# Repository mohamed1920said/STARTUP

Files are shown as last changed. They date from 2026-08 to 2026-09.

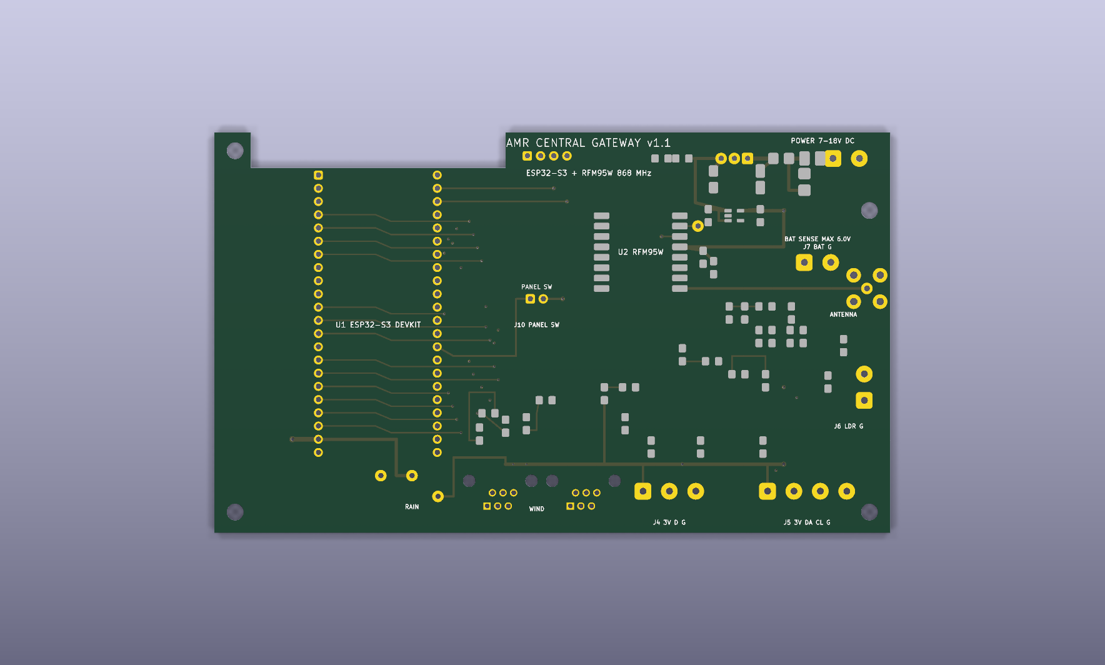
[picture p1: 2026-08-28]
hardware/central_gateway/renders/central_gateway_top.png

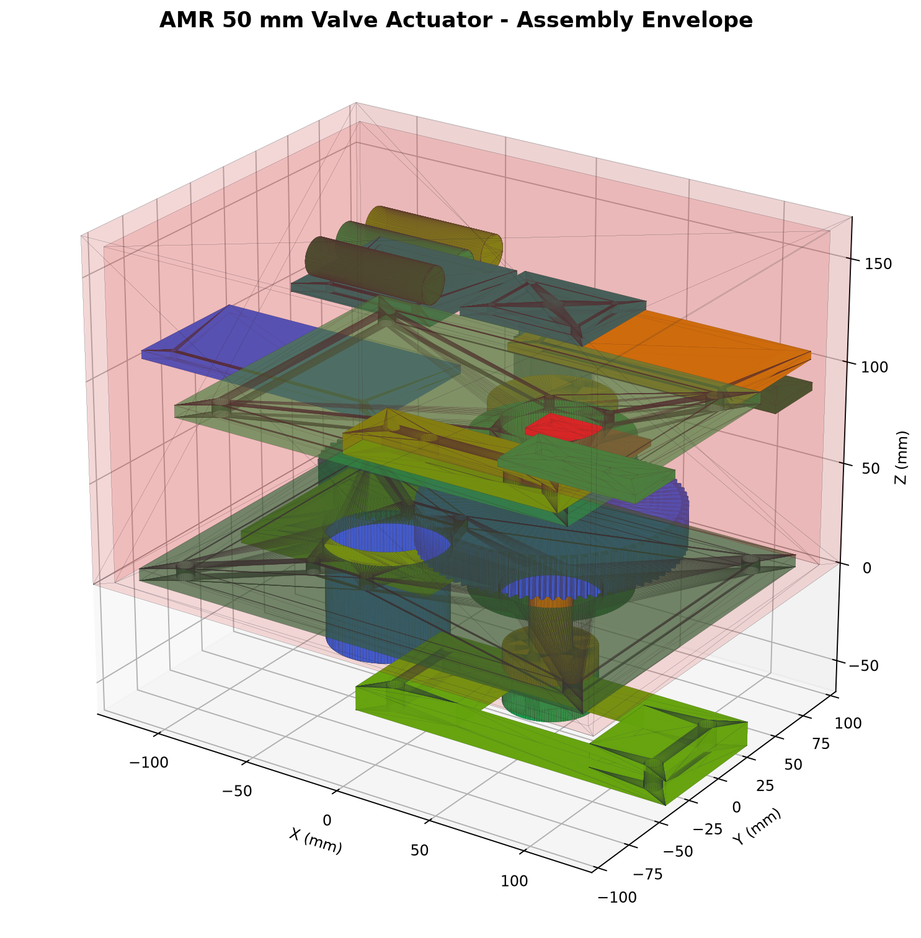
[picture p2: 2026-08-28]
hardware/actuator/cad/renders/AMR_50mm_Valve_Actuator.png

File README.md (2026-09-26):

# AMR LoRa Irrigation System

Supervised-pilot firmware for three device roles:

- ESP32-S3 central gateway
- TTGO LoRa32 soil sensor node
- TTGO LoRa32 actuator/valve node

The gateway receives AES-128-GCM encrypted LoRa telemetry at 868 MHz, serves a local dashboard, runs guarded irrigation rules and an offline ESP32-S3 Edge-AI advisor, controls actuators, records a versioned AI-ready dataset, and optionally connects to an HTTPS cloud API. Cloud control is CLOSE-only, while local MQTT and browser firmware upload are disabled by default for the supervised pilot.

## Firmware environments

| Environment | Hardware | Purpose |
|---|---|---|
| `central_gateway` | ESP32-S3-DevKitC-1-N8 | Gateway, dashboard, weather and optional cloud bridge |
| `sensor_node` | TTGO LoRa32 v2.1 | Soil moisture, DS18B20 temperature and battery telemetry |
| `actuator_node` | TTGO LoRa32 v2.1 | Fail-safe latching-valve control, verified feedback and hydraulic telemetry |

## Wi-Fi setup

1. Power the central gateway.
2. Read the generated commissioning password from the physical 115200-baud serial console.
3. Connect to the WPA2-protected `STARTUP-Gateway-xxxxxx` Wi-Fi network using that password.
4. Open `http://192.168.4.1`.
5. Select farm Wi-Fi and create an 8–32 character dashboard administrator password.
6. After restart, sign in to the dashboard with username `admin` and the configured password.

Use an isolated pilot network. The dashboard, REST API and WebSocket use HTTP Basic authentication. Gateway firmware updates use physical USB in this build.

LoRa reception, local automation, actuator safety and CSV logging continue when
farm Wi-Fi or internet access is unavailable. Dashboard and cloud access
resume after the gateway can boot on the configured farm network.

## Build

```powershell
pio run -e central_gateway -e sensor_node -e actuator_node
pio run -e central_gateway -t buildfs
```

`platformio.ini` pins Espressif32 platform `7.0.1` and exact tested library versions. Do not loosen those constraints for a pilot image; rebuild and repeat the deployment checklist after any dependency change.

## Upload the ESP32-S3 gateway

```powershell
pio run -e central_gateway -t upload --upload-port COM4
pio run -e central_gateway -t uploadfs --upload-port COM4
```

`flash_central.bat COM4` performs both gateway uploads.

This release changes the gateway partition table. The first installation must
upload both firmware and filesystem; uploading only one will leave the
dashboard or partition layout inconsistent.

## Important protocol rule

Gateway, sensor and actuator firmware must be upgraded together. This revision sends the full 16-byte AES-GCM authentication tag; firmware using the former 4-byte tag cannot communicate with it. ACK is 10 bytes and actuator heartbeat is 17 bytes. Persistent sequence reservations and replay checkpoints are written and read back before use; storage failure suppresses transmission or rejects the command/packet instead of continuing without replay protection.

## Node commissioning

Sensor and actuator images contain no default node ID or PSK. Provision each node over its physical USB serial connection, then add the exact same ID, type and unique 16-byte PSK in the gateway dashboard. Duplicate gateway IDs are refused. Reprovisioning requires explicit removal and a newly generated PSK. An unprovisioned or corrupt node keeps its radio disabled, and gateway OPEN remains blocked until it receives a fresh authenticated packet after provisioning. Never clear or clone the preserved `lora_seq` state while reusing a PSK; generate a new PSK after a full NVS erase.

See the [supervised pilot deployment guide](docs/PILOT_DEPLOYMENT.md) for provisioning commands, cloud endpoints and the required bench and field validation.

## Prototype data collection

The authenticated dashboard's **AI Dataset** panel provides:

- raw and centrally calibrated moisture values;
- UTC epoch time, boot ID, uptime and packet sequence for traceability;
- weather, valve commands, verified valve state, ACKs and optional hydraulics;
- crop, growth-stage and soil metadata per sensor zone;
- field event labels such as rain, leak, blockage and valve fault;
- current and previous CSV downloads.

Configure each sensor's real dry/wet ADC endpoints before collecting training
data. The gateway keeps two rolling 1.25 MiB CSV segments as an outage buffer.
Download both segments regularly or configure the HTTPS cloud connection for a
multi-week dataset. See [AI dataset guide](docs/AI_DATASET.md).

Hydraulic inputs are intentionally disabled by default. Wire and calibrate the
real sensors, then build the actuator with `-DENABLE_HYDRAULIC_SENSORS=1`.

## Edge AI

The central gateway now contains a compact trained model bank for irrigation
need, water/runtime recommendation, rain-delay scheduling, soil dry-down,
watering-effect verification, fault detection and next-day weather prediction.
The dashboard **Edge AI** panel explains each zone recommendation.

AI control is deliberately compiled off with `EDGE_AI_ALLOW_CONTROL=0`. The
model runs in shadow mode while the normal threshold controller and actuator
safety limits remain independent. See [Edge-AI model and deployment guide](docs/EDGE_AI.md).

## Project layout

```text
data/                 Dashboard HTML, JavaScript and CSS
docs/                 Current architecture, wiring and security references
hardware/central_gateway/ KiCad 10 carrier PCB, BOM, clean DRC and fabrication files
lib/                  Required Wi-Fi, dashboard, LoRa protocol and crypto libraries
src/central/          ESP32-S3 gateway firmware
src/sensor/           Soil sensor firmware
src/actuator/         Fail-safe valve actuator firmware
platformio.ini        Three retained PlatformIO environments
partitions_8MB.csv     Gateway OTA + 3.375 MiB LittleFS partition map
flash_central.bat     Windows gateway upload helper
upload_guide.txt      Upload commands and recovery notes
```

## Pilot safety limits

Automatic mode can be enabled only after valid valve feedback received within 90 seconds. Invalid sensor data cancels an automatic OPEN that may still be in flight; invalid or stale data retries CLOSE until fresh feedback verifies commanded and physical state are closed. A failed safety enqueue remains eligible at the next pass without starting its throttle; a normal threshold-driven automatic CLOSE retries after five seconds. Pending tracking rejects duplicate live OPENs and never replaces one to make room. The actuator rejects OPEN below 3400 mV or above an implausible 5000 mV reading; CLOSE remains allowed. OPEN is capped at 300 seconds, the build rejects any higher configured cap, and repeated OPEN commands do not extend the active deadline. Failed OPEN feedback verification immediately sends CLOSE and retries it if necessary.

This does not authorize unattended irrigation. A latching valve needs energy to close, software cannot prove water stopped without independent feedback, and the cloud queue is RAM-only with no automatic CSV backlog replay. Keep a physical master shutoff accessible and complete `docs/PILOT_DEPLOYMENT.md` before any wet pilot.

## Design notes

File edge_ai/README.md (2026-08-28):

# Edge-AI training tools

`train_edge_ai.py` trains the compact ESP32-S3 model bank from the Tunisia CSV,
writes `model_manifest.json` and `metrics.json`, and regenerates
`src/central/EdgeAIModel.h`.

`test_edge_ai.py` checks the training hash, model dimensions, dry-versus-wet
behaviour, finite weather forecasts and injected-fault recognition.

`preview_dashboard.py` is a localhost-only visual fixture server for dashboard
QA; it is never included in the ESP32 filesystem image.

See `docs/EDGE_AI.md` for architecture, metrics, safety gates and deployment.

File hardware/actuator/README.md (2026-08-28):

# AMR 50 mm Quarter-Turn Valve Actuator

This directory contains a prototype mechanical design for a 50 mm PVC ball-valve actuator. The gearbox is reusable for a future 63 mm valve; only the lower clamp and measured stem adapter change.

## Release status

Revision `A-PROTOTYPE` is suitable for fit checks, bench testing, and controlled field prototypes. It is **not released for unattended irrigation or sale** until every hold point in `RELEASE_CHECKLIST.md` is closed and the completed actuator passes torque, ingress, electrical, and endurance tests.

The real 5840-31ZY motor and PVC valve were not supplied for measurement. Their interfaces are intentionally marked `HOLD - MEASURE` in the native SolidWorks custom properties and documentation.

## Delivered CAD

- `cad/native/`: 27 manufactured `.SLDPRT` files, purchased-component reference parts, and the resolved 35-component `.SLDASM`.
- `cad/step/`: individual STEP parts and the complete placed STEP assembly.
- `cad/stl/`: printable gears, sensor carriers, trays, and enclosure components.
- `cad/dxf/`: laser/CNC profiles for plates, brackets, and the 50/63 mm clamp variants.
- `cad/renders/`: assembled and exploded verification views plus gear-profile SVGs.
- `cad/motion/`: the verified 6-second open/close GIF, poster, and validation report. Raw viewport frames are deleted after encoding.
- `bom/`: mechanical, material/electrical, and fastener BOMs.

The placed neutral assembly contains 35 components in the 50 mm configuration (the alternative 63 mm clamp is delivered separately). `tools/validate_neutral_assembly.py` performs exact solid-intersection checks and writes `manufacturing/ASSEMBLY_GEOMETRY_VALIDATION.json`. The individual manufactured parts are native feature-based SolidWorks files. Gear bodies use exact 20-degree involute STEP solids generated by `tools/generate_neutral_cad.py` and imported into native parts because the installed SolidWorks 2026 sketch API was unstable on high-segment gear profiles.

The native assembly contains a Basic Motion study named `AMR_Valve_Open_Close`. It drives the 40T motor gear through 180 degrees and the output shaft group through 90 degrees over a 6-second oscillating cycle. The study uses 10 rotary motor features so the output gear, shaft, clutch stack, valve adapter, magnet carrier, reed cam, and manual override remain synchronized. The cover is present in the saved assembly and is suppressed only in the GIF preview.

## Key design values

| Parameter | Value |
|---|---:|
| Valve rotation | 90 degrees |
| Motor gear | 40 teeth, module 1.5, 20-degree pressure angle |
| Output gear | 80 teeth, module 1.5, 20-degree pressure angle |
| Gear ratio | 2:1 |
| Centre distance | 90.00 mm |
| Practical mesh backlash | 0.30 mm total |
| Motor/output gear OD | 63 / 123 mm |
| Nominal output speed | 20 rpm no-load |
| Theoretical 90-degree time | 0.75 s no-load |
| Output shaft | 20 mm, 4140 or stainless |
| Bearings | 2 x 6204-2RS, 20 x 47 x 14 mm |
| Bearing spacing | 59 mm between bearing centres |
| Initial clutch target | 8 N m |
| Production clutch target | 1.5 x measured valve breakaway torque, limited by weakest component |
| Structural plates | 6 mm 6061-T6 |
| Enclosure intent | IP65 minimum, IP67 preferred after testing |

## Mechanical architecture

The 20 mm shaft carries a four-bolt lower flange. A replaceable stem adapter bolts to that flange, so a different stem profile or valve size does not require a new gearbox. Two 16 mm aluminium bearing carriers provide real 6204 seats and internal retainers; the 6 mm structural plates only locate and support the carriers.

The output gear runs on a metal sleeve around the hub and transmits torque through two friction faces. M16 Belleville preload is adjusted until the clutch opens the measured valve reliably and slips before the weakest protected component. The steel M8 stops sit beyond the electronic targets and hard-limit switches.

The requested 19 mm external manual hex cannot physically surround a 20 mm shaft. The manufacturable design uses a 30 mm external hex, 20.2 mm bore, and cross-pin. Engaging manual mode must open a hardware interlock that disables both BTS7960 enable lines.

## Position and safety sequence

1. AS5600 target at calibrated 0 or 90 degrees.
2. Independent reed confirmation near 2 and 88 degrees.
3. Normally-closed hard-limit switch at approximately 0 and 90 degrees.
4. Adjustable steel stop at approximately -1 and 91 degrees.
5. Friction clutch slip.

Hard limits and the manual-mode switch must disable motor-driver control in hardware; software monitoring is additional protection, not the only protection.

## Electronics compatibility warning

The repository's current `src/actuator/main.cpp` drives a short-pulse latching valve through a TB6612FNG. It is **not compatible** with this continuous 12 V 5840-31ZY/BTS7960 actuator. Do not connect this motor to the current firmware. The required I/O and interlock architecture is documented in `INTERFACE_CONTROL.md`.

## Rebuilding

1. Install SolidWorks 2026 with the standard part and assembly templates.
2. Install Python 3.12 and `cadquery==2.6.1`.
3. Run `python tools/generate_neutral_cad.py` to create exact gears, DXFs, neutral assembly, and renders.
4. Run `python tools/validate_neutral_assembly.py`; release only when unintended intersections are zero.
5. Run `cscript //nologo tools/generate_solidworks.vbs <project-root> parts-only`.
6. Run `powershell -ExecutionPolicy Bypass -File tools/build_motion_study.ps1`; this builds the direct native assembly, creates the Basic Motion study, closes and reopens SolidWorks to validate it, captures the cover-off viewport frames, and encodes the GIF preview.
7. Confirm `cad/motion/AMR_Valve_Open_Close_REPORT.txt` ends with `RESULT=PASS`, reports 35 components, 10 motion features after calculation, a 6-second duration, and gear-centre translation below 0.01 mm.
8. Regenerate the drawing pack with `python tools/generate_documentation.py`.

## Required reading

- `ASSEMBLY_INSTRUCTIONS.md`
- `INTERFACE_CONTROL.md`
- `RELEASE_CHECKLIST.md`
- `output/pdf/AMR_Valve_Actuator_Manufacturing_Pack.pdf`

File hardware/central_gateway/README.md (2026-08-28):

# AMR Central Gateway PCB

KiCad 10 carrier board for the AMR central gateway firmware. The board accepts an
ESP32-S3-DevKitC-1-N8R8, adds a soldered RFM95W 868 MHz radio, protected sensor
interfaces, regulated 7-18 V input, an enclosure-button connector, service UART,
and test points.

## Status

- Board revision: `v1.1-prototype`
- Board size: 130 mm x 77 mm, including the ESP32 antenna clearance notch
- Copper layers: 4
- Modular jack footprint: Wuerth Elektronik `615006138421`, manufacturer geometry
- Manufacturing outputs: `manufacturing/central_gateway-fabrication.zip`

The saved DRC result and manufacturing files must be regenerated after every
generator change. This remains a prototype, not a certified production product.
Before sale or outdoor deployment, complete an independent electrical review, RF
tuning, EMC/pre-compliance, surge/EFT/ESD, temperature, and enclosure-ingress tests.

## Physical connector architecture

- J2 is a six-position RJ11-compatible modular jack for the tipping-bucket rain gauge.
- J3 is one six-position RJ11-compatible modular jack for the combined wind cable: wind vane
  plus cup-anemometer reed switch.
- J4 is a three-pin screw terminal for the DHT sensor.
- J5 is a four-pin screw terminal for the BMP280/I2C sensor.
- J6 is a two-pin screw terminal for a passive LDR.
- U2, the RFM95W LoRa module, is soldered directly to the PCB. Its SPI signals are
  intentionally not routed through a screw terminal. J9 is its SMA antenna port.
- The setup/reset button is mounted in the enclosure and wired to J10. There is no
  pushbutton mounted on the PCB.

## Main design choices

- Replaceable ESP32-S3 DevKitC-1 for prototype programming and repair.
- RFM95W-868S2 with a short SMA feed for Tunisia's 868 MHz LoRa deployment.
- 7-18 V input with resettable fuse, SMBJ18A surge clamp, SS34 reverse-polarity
  protection, and R-78E5.0-1.0 5 V regulator.
- AP2112K 3.3 V rail for radio and sensors.
- ESD protection and series resistance on all external sensor signals.
- 100 kOhm / 100 kOhm battery divider matching `WeatherStation.cpp`.
- Dedicated inner ground plane plus bottom ground pour.
- No carrier PCB beneath the ESP32-S3 module antenna.

## Layer stack

| Layer | Use |
|---|---|
| F.Cu | Components, local signals, RF feed |
| In1.Cu | Continuous GND plane |
| In2.Cu | DevKit fan-out and crossing signals |
| B.Cu | Power/signal routing with GND pour |

Order a 1.6 mm, four-layer FR-4 board with at least 1 oz external copper. The
0.45 mm antenna trace is only a prototype starting width. Recalculate the 50 ohm
RF geometry using the fabricator's actual stack-up before production.

## Connector pinout

Pin 1 is the square pad. Modular-jack pin numbers below are PCB contact numbers,
not cable colors; verify the purchased cable continuity before connecting it.

| Connector | PCB pin order | Purpose |
|---|---|---|
| J1 | 1 `VIN_RAW`, 2 `GND` | 7-18 V DC input |
| J2 | 1 NC, 2 NC, 3 `GND`, 4 `RAIN_RAW`, 5 NC, 6 NC | Rain gauge; center pair only |
| J3 | 1 NC, 2 `VANE_RAW`, 3 `GND`, 4 `WIND_RAW`, 5 `GND`, 6 NC | Combined vane + anemometer 6P4C cable |
| J4 | 1 `3V3`, 2 `DHT_RAW`, 3 `GND` | DHT11/DHT22 |
| J5 | 1 `3V3`, 2 `SDA`, 3 `SCL`, 4 `GND` | BMP280 / I2C sensor |
| J6 | 1 `LDR_RAW`, 2 `GND` | Passive LDR; PCB provides 10 kOhm pull-up |
| J7 | 1 `BAT+`, 2 `GND` | 0-6.0 V measurement input only |
| J8 | 1 `3V3`, 2 `GND`, 3 `UART_TX`, 4 `UART_RX` | 3.3 V service UART |
| J9 | center RF, shell `GND` | SMA for tuned 868 MHz antenna |
| J10 | 1 `SETUP_RESET`, 2 `GND` | Enclosure-mounted normally-open button |

Do not power the system through J7 and never apply more than 6.0 V to it. J8 is
3.3 V logic and is not 5 V tolerant. Never apply external voltage to J10: the
panel button must only short pins 1 and 2.

## Weather-kit electrical behavior

- Rain: each bucket tip closes the reed switch and represents 0.2794 mm.
- Wind speed: one closure per second represents approximately 2.4 km/h, or
  0.667 m/s.
- Wind direction: the vane exposes a 16-position resistor network. The firmware
  lookup is calculated for the PCB's 3.3 V, 10 kOhm pull-up; verify and calibrate
  the ADC centers on assembled production hardware.

## Firmware-to-board map

| Function | ESP32-S3 GPIO | PCB net |
|---|---:|---|
| LoRa NSS | 18 | `LORA_NSS` |
| LoRa DIO0 | 2 | `LORA_DIO0` |
| LoRa reset | 14 | `LORA_RST` |
| LoRa SCK / MOSI / MISO | 12 / 11 / 13 | `LORA_SCK` / `LORA_MOSI` / `LORA_MISO` |
| Rain | 6 | `RAIN_GPIO` |
| Wind pulse | 3 | `WIND_GPIO` |
| Wind vane ADC | 10 | `VANE_ADC` |
| DHT data | 7 | `DHT_GPIO` |
| LDR ADC | 9 | `LDR_ADC` |
| Battery ADC | 8 | `BATT_ADC` |
| I2C SDA / SCL | 4 / 5 | `I2C_SDA_GPIO` / `I2C_SCL_GPIO` |
| Wi-Fi setup reset | 0 | `SETUP_RESET` |

Hold the enclosure button for five seconds to request the Wi-Fi setup reset.
GPIO0 is also a boot-strapping pin, so do not hold the button while applying
power or resetting the DevKit unless firmware-download mode is intended.

## Assembly and verification

- TP1: +5 V
- TP2: +3.3 V peripheral rail
- TP3: GND
- TP4: LoRa DIO1

Before fitting U1 or U2, power the carrier from a current-limited bench supply and
verify TP1 and TP2. Fit the ESP32 module, then fit the RFM95W and connect its
antenna before transmitting. Continuity-test both weather cables to confirm their
contact order before plugging them into J2/J3.

Observe diode polarity. D1 cathode connects to `VIN_FUSED`; D2 anode connects to
`VIN_FUSED` and cathode to `VIN_PROTECTED`. For D3-D10, confirm the purchased
part's polarity and marking against the schematic and datasheet.

## Regeneration and verification

From the repository root:

```powershell
python hardware\central_gateway\generate_kicad.py
& 'C:\Program Files\KiCad\10.0\bin\kicad-cli.exe' pcb upgrade hardware\central_gateway\central_gateway.kicad_pcb
& 'C:\Program Files\KiCad\10.0\bin\kicad-cli.exe' pcb drc --refill-zones --save-board --severity-all --format report --output hardware\central_gateway\central_gateway-drc.rpt hardware\central_gateway\central_gateway.kicad_pcb
```

The routed PCB and deterministic generator are authoritative. The legacy
schematic is a compact circuit-review reference and is converted by KiCad on
first open.

## Production checklist

1. Verify the exact DevKit, Wuerth jacks, screw terminals, JST header, and panel
   button against purchased samples and the final enclosure.
2. Confirm cable pinout and add keying/labels so rain and wind plugs cannot be
   exchanged in the field.
3. Tune RF geometry for the chosen stack-up and test the installed antenna/VNA
   performance inside the final enclosure.
4. Validate regulator temperature and brownout margin at maximum Wi-Fi/LoRa load.
5. Test all external ports for the required IEC ESD, EFT, and surge environment.
6. Use a UV-resistant IP65/IP67 enclosure, strain relief, suitable glands or
   sealed panel couplers, conformal coating where appropriate, and fused power.
7. Run a pilot build and production functional-test fixture before volume manufacture.

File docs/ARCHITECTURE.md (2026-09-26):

# AMR System Architecture

## Pilot scope

The maintained build contains one ESP32-S3 central gateway and TTGO LoRa32
sensor/actuator nodes. It is configured for a supervised pilot: Edge AI remains in
shadow mode, local MQTT and browser OTA are disabled, automatic OPEN requires
verified valve-position feedback, cloud control is CLOSE-only, and one OPEN period
is capped at 300 seconds. Compile-time checks prevent a higher configured cap.

```text
Soil sensor nodes -- authenticated LoRa telemetry --> ESP32-S3 gateway
ESP32-S3 gateway -- authenticated LoRa commands --> actuator nodes
Actuator nodes -- authenticated ACK/heartbeat --> ESP32-S3 gateway
Weather sensors --> ESP32-S3 gateway
ESP32-S3 gateway --> authenticated local dashboard + rolling CSV
ESP32-S3 gateway --> optional CA-validated HTTPS cloud API
```

## Central gateway runtime

The Arduino framework runs on ESP-IDF/FreeRTOS. The gateway creates:

- LoRa task: core 1, priority 4, 4096-byte stack.
- Cloud task: core 0, priority 1, 8192-byte stack.
- Dataset task: core 0, priority 1, 6144-byte stack.
- LoRa TX queue: 8 entries.
- Pending command correlation: 32 slots for up to 16 provisioned nodes.
- Cloud request queue: 64 volatile entries.
- Dataset queue: 48 typed records.
- State mutex for persistent downlink sequences and pending commands.

The Arduino loop services Wi-Fi, dashboard maintenance, weather collection, Edge AI
and the automatic controller. LoRa reception, safety logic, and rolling CSV logging
continue without farm Wi-Fi or internet. The setup AP is WPA2 protected with the
generated password printed only on the physical serial console. The farm-network
dashboard uses HTTP Basic authentication; deploy it on an isolated pilot network.

The HTTPS queue retries briefly but is held in RAM. Restart discards queued requests,
and the gateway does not replay CSV records to the cloud. Current and previous CSV
segments remain the outage evidence and must be exported separately.

Cloud `VALVE_ON` commands receive a negative ACK without radio transmission.
`VALVE_OFF` remains enabled. The gateway caches 32 tuples of command ID, target node,
and requested state in RAM. Exact completed duplicates return the cached ACK;
reusing a numeric ID for another node/state is a separate request. Completion also
requires the same tuple, so a delayed old actuator result cannot overwrite a newer
request. A fast ACK that completes the tuple before cloud-pending bookkeeping finishes
cannot downgrade `COMPLETE` back to `PENDING`. The parser validates identifiers before
narrowing them: `command_id` is an integer in 1..`UINT32_MAX`, and `node_id` is an
integer in 1..65534. Invalid values are rejected rather than wrapping to another node.
Rejected commands return a negative ACK, and a pending CLOSE can retry after 30
seconds. The cloud service must still guarantee unique command IDs because this cache
does not survive restart.

## Radio configuration and frame

| Parameter | Value |
|---|---|
| Frequency | 868.0 MHz |
| Bandwidth | 125 kHz |
| Spreading factor | SF9 |
| Coding rate | 4/5 |
| Sync word | `0x12` |
| TX power | 10 dBm |

| Frame field | Size |
|---|---:|
| Node ID | 2 bytes |
| AES-GCM nonce | 12 bytes |
| Packet type | 1 byte |
| Ciphertext | 8–17 bytes for current packet types |
| Authentication tag | 16 bytes, full AES-GCM tag |

Packet types are sensor telemetry `0x10` (12-byte ciphertext), actuator command
`0x20` (8), ACK `0x30` (10), and heartbeat `0x40` (17). Every role must be flashed
from the same revision because the change from the former 4-byte tag changes every
frame length.

## Identity, replay protection, and data flow

Every sensor and actuator is physically provisioned with a role, unique node ID and
16-byte PSK in the `dev_ident` NVS namespace. A missing, corrupt, or wrong-role
identity keeps its radio disabled. The same ID, type, and PSK are entered in the
gateway's authenticated dashboard. There is no radio registration handshake.
Duplicate gateway node IDs are refused. Reprovisioning requires explicit removal
and a fresh PSK so replay history is not silently reset.

Sensor, actuator, and gateway transmitters reserve monotonic sequence ranges in the
`lora_seq` NVS namespace. Receivers track replay state by node and packet stream.
Identity removal preserves sequence state. Erasing or cloning sequence state while
reusing a PSK can repeat an AES-GCM nonce and is prohibited.

Every sequence reservation and replay update that controls acceptance is committed
and read back. Gateway startup stops before command services when the initial
downlink block cannot be verified. Node uplinks stop when no sequence block can be
verified. The actuator leaves radio disabled if replay state cannot load and rejects
a command before movement if its new replay checkpoint cannot be saved. The gateway
rolls back and rejects a received packet when its replay update cannot be persisted.

Authenticated sensor telemetry is checked for replay, centrally calibrated, and
sent to the dashboard, automatic controller, CSV logger, Edge AI shadow advisor,
and optional cloud queue. A moisture error flag, raw ADC outside 10–4000, or a
non-finite/out-of-range calibrated value makes the reading unusable for automatic
control. An invalid reading queues CLOSE even if the cached actuator state still
says closed, cancelling an automatic OPEN that may be in flight. The 30-second retry
clock advances only after CLOSE enters the TX queue; queue failure remains eligible
at the next safety pass. Retries stop only after fresh feedback verifies both
commanded and actual state closed. A verified CLOSE acknowledgement clears older
pending OPEN records by radio sequence but preserves any newer OPEN.

OPEN requires an actuator heartbeat no older than 90 seconds. Automatic OPEN also
requires a valid prediction associated with the actuator, usable moisture data,
verified position feedback, and no actuator fault. Each automatic zone uses a 3%
hysteresis and a 10-second command throttle. Enabling automatic mode itself requires
valid valve feedback no older than 90 seconds. Automatic mode is cleared on gateway
restart and must be explicitly re-armed.

While an automatic zone is believed open, actuator state older than 90 seconds or
linked sensor state older than five minutes triggers CLOSE; the gateway retries that
safety request every 30 seconds. CLOSE remains available when OPEN is rejected. The
actuator independently caps OPEN at 300 seconds and repeated OPEN commands do not
move the original deadline.

Provisioning sets node freshness to unknown. OPEN remains blocked until a fresh
authenticated actuator packet is accepted. The actuator independently rejects OPEN
below 3400 mV and above an implausible 5000 mV reading, while accepting CLOSE. If
OPEN feedback does not verify, it immediately pulses CLOSE and keeps the close
safety timer armed until closure verifies.

The actuator checks its armed local CLOSE timer before testing whether identity or
radio is available. Physical CLOSE retries therefore continue when commissioning
state, replay-storage startup, or LoRa prevents communication; heartbeat reporting
resumes only when identity and radio are ready.

## Command queue integrity

The gateway reserves a pending-correlation slot before inserting an encrypted frame
into the eight-entry LoRa TX queue. The reservation and queue insertion run under the
same state lock. If insertion fails, an unused reservation is cleared; when a newer
CLOSE had selected the oldest CLOSE for replacement, the exact displaced record is
restored. This prevents an ACK from being correlated to a command that was never
queued and prevents a queued command from becoming untracked.

The 32-slot capacity is twice the maximum configured node count of 16; slots are a
shared pool rather than a per-node quota. A second live OPEN for the same node is
rejected. No live OPEN is overwritten when the tracker is full. A new CLOSE may
replace only the oldest live CLOSE, preserving shutdown priority without losing OPEN
correlation. A verified CLOSE clears only older OPEN records by radio sequence and
leaves any newer OPEN intact.

If a normal threshold/hysteresis automatic CLOSE cannot be queued, the gateway
schedules a dedicated retry five seconds later and continues rescheduling at that
interval while queueing fails. Invalid/stale-sensor safety CLOSE uses its separate
safety retry rules described above.

ACK and heartbeat report commanded state, measured state, feedback validity, error
flags, battery, and optional hydraulics. Without position feedback, the state is an
estimate and the actuator is manual-only for this pilot.

## Storage

- `wifi_cfg`: Wi-Fi and dashboard credentials.
- `node_db`: gateway node records, PSKs, automation and replay state.
- `dev_ident`: field-node role, ID, raw PSK and record CRC.
- `lora_seq`: persistent transmit reservations and actuator command replay state.
- `cloud_cfg`: HTTPS URL, API key and trusted CA certificate.
- `field_cfg`: calibration and agronomic metadata per sensor zone.
- LittleFS: dashboard assets plus rolling `dataset.csv` and
  `dataset_previous.csv` files.

The ESP32-S3 uses `partitions_8MB.csv`: two 2.25 MiB application slots, a
3.375 MiB LittleFS partition, and a coredump partition. Each CSV segment is limited
to 1.25 MiB to preserve filesystem headroom.

See `PILOT_DEPLOYMENT.md`, `WIRING.md`, and `SECURITY_HANDSHAKE.md` before field use.

## Reproducible build

All environments pin the Espressif32 PlatformIO platform to `7.0.1`. Library
dependencies are exact, including RadioLib `6.6.0`, PicoMQTT `1.3.0`, ESP Async
WebServer `3.0.6`, ArduinoJson `7.4.3`, DHT `1.4.7`, BMP280 `2.6.8`, Unified Sensor
`1.1.15`, OneWire `2.3.8`, and DallasTemperature `3.11.0`. Update them only as a
coordinated release followed by full rebuild and pilot validation.

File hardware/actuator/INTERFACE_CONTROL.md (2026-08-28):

# Electrical and Mechanical Interface Control

## Electronics architecture

Use a 3S protected battery pack, appropriately rated fuse, BTS7960/IBT-2 class H-bridge, TTGO LoRa32 node, AS5600, and a small I2C GPIO expander such as MCP23017 for redundant discrete inputs.

| Interface | Required implementation |
|---|---|
| Motor | 12 V 5840-31ZY, two power conductors, stall current measured before fuse/driver release |
| BTS7960 | RPWM/LPWM and both enable lines; hardware manual interlock removes enable |
| AS5600 | I2C, mounted on final output shaft, not motor shaft |
| OPEN/CLOSED reeds | Independent dry contacts through protected digital inputs |
| OPEN/CLOSED hard limits | Normally-closed contacts that interrupt the hazardous control direction in hardware and are also monitored |
| Manual mode | Normally-closed hardware driver-disable plus monitored auxiliary contact |
| Battery | 3S1P, 12.6 V maximum; BMS and fuse sized from measured current |
| LoRa | Antenna separated from motor, steel shaft, and high-current conductors |

## Firmware incompatibility

The existing actuator firmware uses a 30 ms TB6612 pulse and one binary feedback input. This mechanical actuator requires a continuous-drive state machine with:

- direction-specific PWM;
- AS5600 angle feedback and magnet diagnostics;
- independent OPEN/CLOSED reed inputs;
- independent normally-closed OPEN/CLOSED limits;
- manual-mode input and hardware inhibit;
- movement timeout, stall/current limit, and no-motion detection;
- calibrated open/closed angles stored in nonvolatile memory;
- commanded, measured, and confirmed state reported separately.

Until that firmware and the corresponding PCB/harness are implemented and tested, the motor must remain disconnected from the current actuator node.

## Harness rules

- Use a separately fused motor supply branch and a regulated logic branch.
- Join grounds at the driver power-entry star point.
- Twist the motor pair and add motor-terminal suppression appropriate to the driver.
- Use shielded or twisted I2C/sensor wiring where cable length requires it.
- Add reverse-polarity, surge, ESD, and undervoltage protection.
- Keep all external inputs within the TTGO board's 3.3 V limits.

## Mechanical hold interfaces

| Interface | Prototype assumption | Required final measurement |
|---|---:|---|
| Motor body | 58 mm reference envelope | diameter, gearbox length, mounting pattern |
| Motor shaft | 8.1 mm D-bore placeholder | diameter, flat depth, projection, tolerance |
| Valve stem socket | 14.3 x 10.3 mm placeholder | profile, across-flats, corner radius, height |
| 50 mm valve neck opening | 72 mm placeholder | neck/body OD and clamp landing width |
| 63 mm valve neck opening | 88 mm placeholder | neck/body OD and clamp landing width |
| Electronics modules | reference envelopes | exact board outline, holes, connectors, heatsink |

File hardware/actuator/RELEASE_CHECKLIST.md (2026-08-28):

# Prototype Release Checklist

Every item must be closed before production or sale.

## Measurements and design

- [ ] Real 5840-31ZY motor body, mounting, shaft, D-flat, and double-shaft projections measured.
- [ ] Real 50 mm valve body/neck, stem, travel, axial float, and clamp landing measured.
- [ ] Real 63 mm valve measured before releasing its clamp configuration.
- [ ] Valve breakaway/running torque measured in both directions, dry/wet, hot/cold, new/aged.
- [ ] Motor no-load, running, stall, and locked-rotor current measured at 9.0, 11.1, and 12.6 V.
- [ ] Gear tooth contact and 0.25-0.35 mm backlash verified over a full revolution.
- [ ] Clutch calibrated and tamper-marked; slip occurs before every protected failure mode.
- [ ] Shaft key/cross-pin, adapter bolts, bearing retention, and M8 stops added per drawings.

## Electronics and firmware

- [ ] BTS7960 or production-equivalent driver qualified at measured stall current and enclosure temperature.
- [ ] BMS, cell holder, wiring, connector, and fuse qualified for measured current.
- [ ] Continuous-drive actuator firmware implemented; TB6612 pulse firmware is not used.
- [ ] AS5600 plausibility, magnet loss, no-motion, reversed-motion, timeout, and stall faults tested.
- [ ] Both NC hard limits independently interrupt hazardous motion in hardware.
- [ ] Manual override independently disables the motor driver in hardware.
- [ ] Loss of radio, MCU reset, brownout, sensor disconnect, and stuck output tested safely.

## Environmental and production

- [ ] IP65/IP67 ingress test completed on production-intent enclosure, glands, gasket, and vent.
- [ ] Condensation/drainage, UV, salt/corrosion, temperature, vibration, and drop tests completed.
- [ ] LoRa range and EMC pre-compliance tests completed with motor starting and stalled.
- [ ] Printed PA-CF moisture conditioning and dimensional process documented.
- [ ] 500-cycle engineering test and 5,000-cycle pilot endurance test passed.
- [ ] Risk assessment, installation manual, maintenance interval, labels, traceability, and warranty process approved.
- [ ] Applicable Tunisian electrical, radio, battery transport, environmental, and product-safety obligations reviewed by qualified professionals.

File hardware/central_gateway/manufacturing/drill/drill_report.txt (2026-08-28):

Drill report for central_gateway.kicad_pcb
Created on 2026-08-08T20:58:44

Copper Layer Stackup:
    =============================================================
    L1 :  top_cu                    front
    L2 :  gnd_plane                 in1
    L3 :  signals                   in2
    L4 :  bottom_cu                 back

Drill file 'central_gateway-PTH.drl' contains
    plated through holes:
    =============================================================
    T1  0.300mm  0.0118"  (88 holes))
    T2  0.400mm  0.0157"  (5 holes))
    T3  0.450mm  0.0177"  (1 hole)
    T4  0.500mm  0.0197"  (2 holes))
    T5  0.600mm  0.0236"  (1 hole)
    T6  0.900mm  0.0354"  (12 holes))
    T7  1.000mm  0.0394"  (57 holes))
    T8  1.100mm  0.0433"  (1 hole)
    T9  1.300mm  0.0512"  (13 holes))
    T10  1.400mm  0.0551"  (4 holes))

    Total plated holes count 184

Drill file 'central_gateway-NPTH.drl' contains
    unplated through holes:
    =============================================================
    T1  2.360mm  0.0929"  (4 holes))
    T2  3.200mm  0.1260"  (4 holes))

    Total unplated holes count 8

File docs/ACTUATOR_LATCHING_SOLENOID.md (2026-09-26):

# Actuator: 4.5 V latching solenoid

The actuator uses the PlatformIO `ttgo-lora32-v21` board definition. Its onboard
SX1276 reset is GPIO23, so GPIO23 must never drive the valve.

| Signal | Configured GPIO |
|---|---:|
| LoRa reset | 23 |
| Driver AIN1 | 2 |
| Driver AIN2 | 4 |
| Driver PWMA | 12 |
| Driver STBY | 17 |
| Position feedback | Disabled by default (`0xFF`) |

Confirm the physical PWMA wire is on GPIO12. The former reference mapping with
PWMA on GPIO23 conflicts with radio reset and cannot be used.

The firmware sends a 30 ms polarity-reversing pulse. It does not regulate or measure
the solenoid drive voltage. Verify coil pulse duration, current, supply, driver
rating, and polarity against the actual parts before connecting water.

## Identity and startup

The generic actuator image has no default ID or PSK. On boot it configures safe
outputs and attempts a CLOSE pulse before enabling radio. A missing, corrupt, or
wrong-role identity keeps radio disabled and leaves the physical serial provisioning
console available. See `PILOT_DEPLOYMENT.md` for commands.

Because a latching valve can retain position through controller reset, a boot CLOSE
pulse is only an attempt. Loss of power can prevent a later powered close. Keep an
accessible upstream manual shutoff.

Replay state must load successfully before radio is enabled. Each accepted command's
new replay checkpoint is committed and read back before any valve pulse; failure
rejects the command. Uplink sequence blocks are also verified before ACK/heartbeat
transmission.

## Pilot runtime and feedback behavior

Every valid OPEN carries a timeout from 1 to 300 seconds. The default and absolute
maximum are 300 seconds. The actuator arms the deadline before the first OPEN pulse.
A repeated OPEN pulse does not extend the original deadline. At expiry, it attempts
CLOSE independently of the gateway's inferred state.

The 300-second ceiling is enforced twice: authenticated commands above it are
rejected, and a compile-time assertion rejects `PILOT_MAX_OPEN_S` above 300. Before
an OPEN pulse, the actuator samples its battery. It rejects OPEN below 3400 mV and
also rejects an implausible reading above 5000 mV, which can indicate divider or ADC
misconfiguration. CLOSE bypasses this battery gate so shutdown remains available.

With position feedback enabled, the actuator reads it after every command and before
every 30-second heartbeat. A mismatch sets the fault flag. If feedback reports OPEN
while the command is CLOSED, the safety loop schedules immediate CLOSE and retries
a failed close after five seconds. If an OPEN pulse does not verify as open, the
actuator immediately sends a CLOSE pulse because the feedback fault is ambiguous;
it keeps retrying CLOSE if closure also fails verification.

The armed CLOSE timer is serviced before the main loop checks identity or radio.
Local physical CLOSE retries therefore continue even when the node is unprovisioned,
replay storage prevented radio startup, or LoRa is unavailable. Only the follow-up
heartbeat is skipped while communications are unavailable.

The current default build has no position switch:

- ACK and heartbeat report `feedback_valid=0` and
  `ACT_ERR_FEEDBACK_MISSING`.
- State is the requested/estimated state, not a physical measurement.
- ACK result `0x02` means `PULSE_SENT_UNVERIFIED`; it does not mean the valve moved.
- The gateway UI reports feedback unavailable and blocks automatic OPEN.
- Manual commands remain available for attended bench and pilot tests.

ACK result values are `0x00` verified, `0x01` feedback mismatch, `0x02` pulse sent
without feedback, `0x03` invalid authenticated command, `0x04` OPEN rejected for a
low or implausible battery reading, and `0x05` replay-storage/NVS persistence
failure. Result `0x05` rejects the command before any valve actuation. An
unauthenticated, wrong-type, wrong-length, wrong-node, or replayed radio frame is
dropped.

To use GPIO3 as an active-low dry-contact OPEN signal, wire and bench-test the switch
described in `WIRING.md`, then add this actuator build flag:

```ini
-DACTUATOR_VALVE_FB_PIN=3
```

The feedback signal must be electrically safe for 3.3 V GPIO and must reflect the
physical valve position. Do not enable automatic mode until both OPEN and CLOSE
feedback transitions have passed the deployment checklist.

## Hydraulic inputs

Flow, pressure, tank, and current inputs remain disabled unless built with
`-DENABLE_HYDRAULIC_SENSORS=1`. Disabled inputs use explicit sentinel values and set
the hydraulics-disabled flag. Enabling them requires real signal conditioning and
calibration; analog inputs must not exceed 3.3 V.

## Verification

Build the firmware and perform the dry hardware tests in `PILOT_DEPLOYMENT.md`:

```powershell
pio run -e actuator_node
pio run -e actuator_node -t upload --upload-port COM_PORT
pio device monitor --port COM_PORT --baud 115200
```

Confirm the port and wiring before upload. A successful firmware build or host test
does not certify the valve, driver, power system, enclosure, or hydraulic shutdown.

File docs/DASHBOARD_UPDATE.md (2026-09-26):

# Central reliability and dashboard update

## Screens and design intent

The dashboard is a local web interface served by the ESP32-S3. It follows familiar iOS layout conventions using the device's system font, neutral grouped backgrounds, restrained green actions, and generous spacing. It is not a native iOS application.

| Screen | Layout and purpose | Typography and interaction | iOS reasoning |
| --- | --- | --- | --- |
| Overview | Current weather observation, irrigation next step, then supporting station measurements. | Large title; large, light temperature; smaller secondary labels. A single link opens irrigation details. | A clear hierarchy helps the farmer understand the immediate situation without scanning technical panels. |
| Irrigation | Field recommendations, experimental local weather estimate, then valve controls. | Grouped answers with short status labels. Opening a valve requires confirmation; commands remain unverified without physical feedback. | Keep related decisions together and distinguish a request from its physical result. |
| Devices | Soil readings and per-session moisture history. | System text and simple measurement rows. Device management is a separate link. | Familiar grouped information keeps routine observation separate from setup. |
| Settings | Gateway diagnostics and expandable device, field, cloud, update and log groups. | Standard form controls; disclosure sections; clear primary and destructive actions. | Progressive disclosure keeps infrequent administration out of the daily view. |

Mobile navigation uses four persistent bottom tabs, with safe-area padding. Desktop uses a sidebar with the same destinations. Controls have a minimum 44px touch target; inputs use 16px text. System dark mode is supported. Motion is limited to brief state transitions and toast entry, and respects reduced-motion preferences. Native browser confirmation dialogs and disclosure controls provide predictable keyboard behavior. No external fonts, icon scripts, maps or third-party dashboard libraries are required.

Design references: [Apple layout guidance](https://developer.apple.com/design/human-interface-guidelines/layout), [typography](https://developer.apple.com/design/human-interface-guidelines/typography), [tab bars](https://developer.apple.com/design/human-interface-guidelines/tab-bars).

## Reliability changes

- Radio receive work is queued. Decryption, recommendations, dataset records and optional MQTT publication run in the 16 KiB Arduino loop task instead of inside the 4 KiB radio task. Local MQTT is disabled in the supervised-pilot build. Task allocation failures are reported.
- Shared node/field/AI state is synchronized and node snapshots avoid using changing array pointers across tasks.
- Wi-Fi retries after a router or connection interruption. WebSocket output applies backpressure; background browser tabs release their connection and reconnect on return.
- An authenticated `/api/telemetry` snapshot restores weather, sensor and actuator cards after refresh. Snapshot age preserves staleness instead of making an old reading look newly received.
- Dashboard polling is sequential, bounded by timeouts and paused when the page is hidden. Gateway restart detection clears old readings. Connection loss is visible separately from missing sensor data.
- Invalid soil readings remain visible with a reason. Missing or stale weather produces unavailable values rather than a fictitious zero-rain forecast. Model-driven runtime and rain delay require the appropriate inputs.
- The no-feedback actuator's capability flags no longer falsely imply a stuck valve. Missing hydraulic/position sensors limit fault checks; inferred valve state is not a measured position.

## Verification and practical limits

Host tests compile the production C++ engine and relevant central methods against hardware stubs. Browser tests use deterministic, explicitly labeled demo data. They cover missing readings, unavailable forecasts, view navigation, mobile overflow, failed control requests and disconnection states. These tests do not establish field accuracy or physically verify valve movement.

Run from the project directory:

```powershell
& "$env:USERPROFILE\.platformio\penv\Scripts\python.exe" tests/test_ai_readiness.py
& "$env:USERPROFILE\.platformio\penv\Scripts\python.exe" tests/test_central_reliability.py
& "$env:USERPROFILE\.platformio\penv\Scripts\python.exe" edge_ai/preview_dashboard.py --port 8766
# In another terminal, with Playwright available:
node tests/test_dashboard.cjs
```

Preview: `http://127.0.0.1:8766`. Demo values are never sent to the central or its LoRa nodes.

Firmware and dashboard must be deployed together. PlatformIO environment: `central_gateway`; filesystem: LittleFS. The current partition layout uses the first 8 MiB even when the detected module has 16 MiB flash. Do not change the partition layout as part of a routine update.

Uploading a filesystem image replaces files in that partition, including stored datasets. The 2026-09-11 COM5 update was preceded by a full 16 MiB backup in `tmp/device_backups/central_COM5_20260911_e072a1d5386c/`. That ignored directory may contain private device configuration and must not be committed or published.

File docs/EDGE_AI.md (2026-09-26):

# ESP32-S3 Edge-AI Irrigation Model

## Status

The gateway contains a trained compact model bank and runs inference locally,
without internet access. The current model is intentionally compiled in
**shadow mode** because weather inputs are ERA5 reanalysis and device/control
labels are deterministic prototype simulations, not measurements from a
calibrated farm installation.

Shadow mode displays and logs recommendations but does not let the AI issue a
valve command. Existing threshold automation remains available independently.

## Questions answered

| Farmer question | Gateway output |
|---|---|
| Does this field need irrigation now? | `irrigation_needed`, `irrigation_now`, probability and explanation |
| How long should watering run? | water depth, total duration, 300-second pilot command cycles and cycle count |
| Can irrigation wait? | rain-delay flag, slow-drying flag and wait hours |
| Did watering increase soil moisture? | pending, moisture increased, or no response, with measured percentage-point change |
| Is equipment unhealthy? | leak, blocked pipe, empty tank, stuck valve, sensor fault or weak battery |
| What is the schedule? | now, cooler start window, 12-hour slow-drying delay, or 24-hour rain delay |
| What weather is expected? | next-day temperature, rain amount/probability and ET₀ |

## Architecture

The model is a hybrid design:

1. Small standardized logistic and ridge models generate irrigation, water,
   drying and weather estimates.
2. A compact multi-class model scores hydraulic/device faults.
3. Deterministic safety rules override model output for valve disagreement,
   impossible sensor values, low batteries, empty tanks and abnormal flow.
4. Runtime is calculated from predicted millimetres, configured zone area and
   total emitter flow. The supervised-pilot actuator caps a command at 300 seconds.
5. The actuator's own timeout and feedback protections remain authoritative.

Model code:

- `src/central/EdgeAIEngine.h`
- `src/central/EdgeAIEngine.cpp`
- generated coefficients in `src/central/EdgeAIModel.h`

## Model inputs

Irrigation inference uses calibrated soil moisture and trend, moisture
threshold, soil temperature, local temperature/humidity/pressure/rain/wind,
estimated VPD and ET₀, crop coefficient, recent rain and seasonality.

Runtime also requires valid values for:

- zone area in square metres;
- combined emitter flow in litres per hour.

The gateway refuses AI runtime control when either value is zero.

Fault inference combines raw/calibrated moisture, batteries, RSSI, valve
command and actual state, feedback validity, flow, pressure, tank level, pump
current and firmware error flags. Missing optional hydraulic sensors remain
`NAN` and do not become false zero readings.

## Scheduling policy

- Critically dry soil, defined as at least 12 percentage points below the zone
  threshold, bypasses weather and slow-drying delay logic.
- Otherwise, predicted rain of at least 1.5 mm with rain probability above the
  trained threshold delays irrigation for 24 hours.
- A drying rate above -0.7 percentage points/day with ET₀ below 4 mm/day delays
  irrigation for 12 hours.
- Non-critical watering is scheduled in a cooler 05:00-09:00 or 19:00 window.
- Long applications must be split into 300-second pilot cycles. Hydraulic hardware must
  provide the spacing and pressure capacity required for multiple cycles.

## Watering-effect verification

When verified actuator feedback changes from closed to open, the gateway saves
the current soil moisture. After the valve closes:

- an increase of at least 1.5 percentage points is reported as
  `moisture_increased`;
- the result stays `pending` for up to two hours;
- no sufficient increase after two hours is reported as `no_response` and
  raises a diagnostic warning.

This check is useful for detecting ineffective irrigation, but it does not
replace independent flow metering or manual agronomic verification.

## Weather prediction

The embedded forecast uses a compact next-day model trained on daily Tunisia
ERA5 records. Local 30-second weather readings are aggregated to daily means
and rainfall totals before inference. The model predicts:

- next-day mean air temperature;
- next-day rain amount;
- probability of at least 1 mm rain;
- next-day reference evapotranspiration (ET₀).

This is a local fallback forecast, not a replacement for a high-resolution
numerical weather service. A production scheduler should combine it with a
trusted forecast API when connectivity is available and retain the local model
for offline operation.

## Validation results

Training uses 2023-2024 records. The complete year 2025 is held out, preventing
random leakage from adjacent days.

| Output | 2025 holdout result |
|---|---|
| Irrigation decision | 86.16% accuracy, 84.24% recall, 15.76% false-negative rate |
| Recommended water | 1.71 mm MAE across 203 irrigation events |
| Next-day temperature | 0.98 °C MAE |
| Next-day rain amount | 1.21 mm MAE |
| Next-day ET₀ | 0.55 mm MAE |
| Rain occurrence | 72.48% recall, 30.50% precision |

Fault scores are high on injected synthetic conditions, but the 2025 holdout
does not contain every fault class. Fault metrics therefore do not qualify the
model for unattended commercial control.

Machine-readable results are in `edge_ai/metrics.json`; model coefficients,
features, hashes and governance metadata are in
`edge_ai/model_manifest.json`.

## Train and test

Use the bundled Python environment or any Python installation with NumPy and
pandas:

```powershell
python edge_ai/train_edge_ai.py
python -m unittest -v edge_ai/test_edge_ai.py
pio run -e central_gateway
```

Training is deterministic. It regenerates the model header, manifest and
metrics from the CSV. The firmware embeds the dataset SHA-256 hash so a deployed
model can be traced to its training artifact.

## Dashboard and API

The dashboard **Edge AI** panel shows forecasts and one recommendation card per
sensor zone. Current state is available from authenticated endpoint:

```text
GET /api/ai/status
```

Live messages use WebSocket types `ai_weather` and `ai_prediction`.

AI outputs are also appended to dataset schema version 3. When upgrading from
schema 2, the gateway moves the existing current CSV to the downloadable
previous segment before creating a schema-3 file; this prevents mixed-width
CSV rows.

## Enabling AI control

Current `platformio.ini` explicitly sets:

```ini
-DEDGE_AI_ALLOW_CONTROL=0
```

Do not change it until all of the following are complete:

1. Replace or augment synthetic device columns with calibrated prototype data.
2. Collect farmer-verified irrigation and fault labels across representative
   Tunisian farms, crops, soils and seasons.
3. Retrain and repeat temporal and farm-level holdout tests.
4. Run shadow mode and compare recommendations with agronomist/farmer actions.
5. Verify leak/blockage false-negative rates and watering-effect behaviour.
6. Test valve feedback, maximum runtime, brownout, empty-tank, pump and offline
   fail-safe behaviour on the actual hydraulic installation.
7. Approve the model version and dataset hash in a documented release process.

Keep `EDGE_AI_ALLOW_CONTROL=0` throughout this supervised pilot. A later control
trial requires a separately reviewed release after every gate above passes. Never
remove actuator timeout, feedback, flow, pressure or battery protection.

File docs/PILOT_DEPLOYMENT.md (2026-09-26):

# Supervised Pilot Deployment

## Scope

This build is for a supervised pilot. Keep a trained operator at the installation,
keep a physical master shutoff accessible, and verify every safety action on a dry
bench before connecting the valve to irrigation water. The firmware limits an
OPEN command to 300 seconds, blocks automatic OPEN without verified valve-position
feedback, rejects OPEN when the actuator heartbeat is older than 90 seconds, and
requests CLOSE when an automatic zone loses actuator state or its sensor becomes
stale. These controls reduce risk; they do not prove that a latching valve moved or
that water stopped.

The actuator also rejects OPEN when its measured battery is below 3400 mV or above
an implausible 5000 mV; CLOSE remains accepted. Remote cloud control is CLOSE-only
in this build. Local dashboard OPEN remains an attended action subject to the same
actuator freshness, battery, feedback, and timeout protections.

The actuator's local timeout/CLOSE loop runs before the identity/radio availability
check. Once armed, it continues physical CLOSE attempts even if NVS identity or LoRa
is unavailable; only its status transmission depends on radio.

An actuator built without position feedback is available for supervised manual
testing only. Its ACK confirms that an electrical pulse was sent. It cannot confirm
valve movement. Do not enable automatic irrigation for that actuator.

## Hardware gates

Complete these checks before any wet test:

- Fit an accessible manual upstream shutoff and confirm the operator can isolate
  the zone without the gateway, actuator, network, or battery.
- Confirm valve type, pulse polarity, 4.5 V coil requirements, driver current,
  supply capacity, flyback/current paths, and every GPIO against the actual parts.
- Fit and test independent valve-position feedback for automatic operation.
- Dry-cycle OPEN and CLOSE, remove radio/Wi-Fi/cloud connectivity, reset each
  controller, and interrupt power at each stage.
- Validate brownout behavior, actuator battery limits, weatherproof enclosure,
  cable strain relief, fusing, moisture ingress protection, and antenna clearance.
- Keep `EDGE_AI_ALLOW_CONTROL=0`. Edge AI is a shadow advisor during this pilot.
- Do not leave the installation unattended until the validation checklist below
  passes on the installed hardware and the pilot owner accepts the results.

## Build all coordinated firmware

Install PlatformIO, open a PowerShell terminal in the repository root, and run:

```powershell
pio run -e central_gateway -e sensor_node -e actuator_node
pio run -e central_gateway -t buildfs
```

The tested dependency set is pinned in `platformio.ini`:

| Component | Pinned version |
|---|---|
| Espressif32 PlatformIO platform | `7.0.1` |
| RadioLib | `6.6.0` |
| PicoMQTT | `1.3.0` |
| ESP Async WebServer | `3.0.6` |
| ArduinoJson | `7.4.3` |
| DHT sensor library | `1.4.7` |
| Adafruit BMP280 Library | `2.6.8` |
| Adafruit Unified Sensor | `1.1.15` |
| OneWire, sensor node only | `2.3.8` |
| DallasTemperature, sensor node only | `3.11.0` |

Keep these exact constraints for the pilot. Any platform or dependency update needs
a clean rebuild of all roles and repetition of the full validation checklist. Both
gateway and actuator contain compile-time checks that reject a configured pilot OPEN
cap above 300 seconds.

The gateway, sensors, and actuators use a full 16-byte AES-GCM authentication tag.
Flash all roles from this same revision. Firmware with the former 4-byte tag cannot
communicate with this revision.

Upload the gateway firmware and LittleFS dashboard, replacing `COM_GATEWAY` with
the confirmed port:

```powershell
pio run -e central_gateway -t upload --upload-port COM_GATEWAY
pio run -e central_gateway -t uploadfs --upload-port COM_GATEWAY
pio device monitor --port COM_GATEWAY --baud 115200
```

Upload node firmware with each board's confirmed port:

```powershell
pio run -e sensor_node -t upload --upload-port COM_SENSOR
pio run -e actuator_node -t upload --upload-port COM_ACTUATOR
```

Do not infer a COM port from an earlier installation. Close any serial monitor using
the port before uploading.

## Provision each field node over physical USB

Sensor and actuator binaries contain no shared default identity. An empty, corrupt,
or role-mismatched identity keeps the node radio disabled. The actuator first puts
its outputs into a safe state and attempts a CLOSE pulse.

Generate a different random 16-byte PSK for every node and store it in the pilot
asset register:

```powershell
py -c "import secrets; print(secrets.token_hex(16).upper())"
```

Connect the node by USB and open a 115200-baud serial monitor. Commands are
uppercase and end with Enter:

```text
STATUS
PROVISION 0001 <32_HEX_SENSOR_PSK>
```

Use a unique four-digit hexadecimal ID other than `0000` or `FFFF`, and replace the
example PSK. Sensor and actuator IDs must also be unique from one another. The node
prints its role, state, ID, and chip identity but never prints the PSK. It restarts
after successful provisioning.

To replace a valid identity, connect by physical USB and run:

```text
UNPROVISION 0001 CONFIRM
```

If `STATUS` reports `corrupt` or `role_mismatch`, recover with:

```text
ERASE CORRUPT CONFIRM
```

Identity removal deliberately preserves the `lora_seq` NVS namespace. Never clear,
restore, or clone sequence state while keeping the same PSK: doing so can reuse an
AES-GCM nonce. After a full flash erase or NVS replacement, provision a newly
generated PSK at both ends.

Sequence and replay writes are verified by reading NVS back. Treat any serial
`sequence`, `replay storage`, or `storage error` message as a no-go condition:

- gateway startup stops before command services if it cannot reserve downlink
  sequence space;
- the actuator keeps radio disabled if replay state cannot be loaded;
- an actuator command is rejected without actuation if its replay checkpoint cannot
  be saved; ACK result `0x05` means replay-storage/NVS persistence failure;
- sensor/actuator uplinks are not transmitted without a verified sequence block;
- the gateway rejects a received packet if its updated replay checkpoint cannot be
  committed and verified.

The deep-sleep sensor exposes a short serial maintenance window after a physical
reset. Start the serial monitor before reset. A timer wake sends telemetry and
returns to sleep without opening this window. An unprovisioned sensor remains awake
with its radio disabled so it can be commissioned.

## Configure the gateway

On first boot, keep the gateway connected to a physical serial monitor. The serial
log prints a unique `STARTUP-Gateway-xxxxxx` SSID and its generated commissioning
password. Connect to that WPA2-protected AP, open `http://192.168.4.1`, select the
farm network, and create an 8–32 character dashboard administrator password. After
restart, sign in as `admin` on the gateway's farm-network address.

Use an isolated pilot network. The local dashboard uses HTTP with Basic
authentication. Local MQTT and browser firmware upload are disabled by default in
the supervised pilot build. Perform firmware updates over physical USB.

In **Settings → Devices**, add each node using the exact ID, type, and PSK recorded
during USB provisioning. Keys consisting entirely of `00` or `FF` are rejected.
The gateway refuses an ID that is already registered. To reprovision, first remove
the gateway record, physically `UNPROVISION` the node, generate a new PSK, and then
provision both ends again. Do not overwrite an existing record because doing so
would reset its replay history.

Provisioning alone does not mark a node online: its gateway `lastSeen` starts empty.
Wait for a fresh authenticated packet from that physical node before any command
test. Link each actuator to its sensor. The moisture threshold range is 5–95%.
Automatic mode is cleared on every gateway restart and must be re-armed by the
operator only after fresh sensor telemetry and valid actuator feedback have been
observed. Enabling automatic mode is rejected unless valid valve feedback was
received within the previous 90 seconds.

For an invalid or stale linked sensor, the gateway keeps requesting CLOSE while an
OPEN is pending or closure is not verified. It records the 30-second retry time only
after the CLOSE was successfully queued, so a full/unavailable TX queue remains
eligible at the next safety pass. Retries stop after fresh feedback reports both
commanded and actual state closed. When that verified CLOSE ACK arrives, the gateway
removes only pending OPENs with an older radio sequence; it preserves a newer OPEN
so an earlier CLOSE response cannot erase a later command.

The gateway has 32 pending command slots for at most 16 nodes. It reserves the
pending record before placing a frame in the eight-entry LoRa TX queue. Reservation
and queue insertion are one locked transaction: if queue insertion fails, an unused
slot is cleared or the exact oldest CLOSE displaced by a newer CLOSE is restored.
A duplicate live OPEN for the same actuator is rejected, and a live OPEN is never
overwritten to free a slot. When all slots are occupied, only a newer CLOSE may
replace the oldest CLOSE. This keeps OPEN/ACK correlation intact while giving
shutdown commands priority.

A normal moisture-threshold transition from OPEN to CLOSE has a dedicated recovery
path: if its first enqueue fails, the gateway schedules another attempt after five
seconds and repeats that schedule while queueing fails. This is separate from the
invalid/stale sensor safety CLOSE throttle above.

## Optional HTTPS cloud connection

In **Settings → Cloud**, enter:

- an `https://` base URL without a trailing slash;
- the API key sent as `X-API-Key`;
- the PEM CA certificate used to validate the server.

Plain HTTP, a missing API key, or a missing CA certificate disables cloud transfer.
The server contract is:

| Method | Endpoint |
|---|---|
| `POST` | `/api/ingest/telemetry` |
| `POST` | `/api/ingest/heartbeat` |
| `POST` | `/api/ingest/weather` |
| `POST` | `/api/ingest/register-node` |
| `POST` | `/api/ingest/ack` |
| `GET` | `/api/commands/pending` |

For example, the telemetry request body contains the centrally calibrated reading
and its trace fields:

```json
{
  "node_id": 1,
  "moisture_raw": 2134,
  "moisture": 47.25,
  "temperature": 23.80,
  "battery": 3.921,
  "sequence": 1057,
  "error_flags": 0,
  "rssi_dbm": -91,
  "epoch_ms": 1780000000000
}
```

The gateway polls commands about every 10 seconds. Each command object needs
`command_id`, `node_id`, and an action. Return a JSON array such as:

```json
[
  {"command_id": 42, "node_id": 2, "action": "VALVE_OFF"}
]
```

The cloud parser accepts only `VALVE_ON` and `VALVE_OFF`, but this supervised-pilot
build rejects every `VALVE_ON` without transmitting an OPEN and posts a negative ACK.
`VALVE_OFF` remains enabled and is the only remote control action the pilot server
should send.

The parser validates identifiers before converting them to radio-sized values.
`command_id` must be an integer from 1 through 4294967295 (`UINT32_MAX`), and
`node_id` must be an integer from 1 through 65534. Non-integer, negative, zero, and
out-of-range identifiers are rejected, so an oversized value cannot wrap and target
another node.

The gateway keys idempotency by the tuple `(command_id, node_id, requested_state)`.
Repeating the same completed tuple does not actuate again; it returns the cached
positive or negative ACK. Reusing a numeric command ID for a different node or state
does not suppress that new request. A delayed actuator completion is accepted only
when all three fields still match, so an old ACK cannot complete or acknowledge the
newer tuple. A pending CLOSE may retry after 30 seconds, while the same pending tuple
is otherwise ignored. This bounded cache is volatile across gateway restart, so the
cloud service must still issue unique command IDs and retain outcomes. If a fast
actuator ACK completes an exact tuple before its cloud-pending bookkeeping finishes,
the completed state remains terminal and is never downgraded to pending.
The ACK `ok` field is true only for actuator result `0x00`, meaning position was
verified. A no-feedback CLOSE pulse therefore returns `ok:false` even though the
electrical pulse was sent; an operator must verify physical closure.

The cloud request queue contains 64 entries in RAM and retries a failed request a
limited number of times. It is lost on restart and does not replay the LittleFS CSV
backlog. Rolling local CSV is the outage record; export both current and previous
segments regularly or implement server-side ingestion of exported files.

## Validation checklist

Record the result, firmware commit, device IDs, operator, date, and measured valve
behavior for every item:

1. Confirm all three roles were built and flashed from the same revision and that
   packets authenticate with the 16-byte tag.
   Force an NVS write/readback failure in a test build or fault harness and verify
   sequence transmission/command processing stops rather than using an unreserved
   or uncheckpointed counter.
2. Confirm the commissioning AP requires the serial-displayed password and the
   dashboard requires the configured administrator password.
3. Confirm an unprovisioned, corrupt, or wrong-role node keeps its radio disabled.
   Confirm a duplicate gateway ID is refused. Remove both identity records, use a
   new PSK, and confirm clean reprovisioning.
4. Confirm sensor and actuator IDs/PSKs match the gateway. Verify OPEN is blocked
   immediately after registration, then confirm a fresh authenticated packet and
   30-second actuator heartbeat make the node current.
5. Issue an automatic OPEN and, before its ACK, disconnect or short the moisture
   probe so it reports an error or raw ADC outside 10–4000. Verify the in-flight
   OPEN is cancelled by CLOSE. Confirm later invalid packets can retry CLOSE after
   the 30-second safety throttle.
6. Verify automatic mode cannot be enabled without valid position feedback received
   within 90 seconds. Let feedback age beyond 90 seconds, verify re-arm is rejected,
   and confirm automatic mode starts disabled after every gateway restart.
7. Attempt OPEN after the actuator heartbeat has been absent for more than 90
   seconds. Verify rejection. Confirm CLOSE remains available.
8. While an automatic zone is open, stop sensor telemetry for more than five
   minutes and verify CLOSE requests repeat no faster than every 30 seconds after
   successful queueing. Fill/disable the TX queue and confirm a failed enqueue does
   not start the throttle. Restore feedback and verify retries stop only after both
   commanded and actual state are verified closed. Repeat with the actuator
   heartbeat absent for more than 90 seconds.
   Separately force the normal threshold-driven CLOSE enqueue to fail and verify a
   retry is attempted after five seconds.
9. Request a runtime above 300 seconds and verify rejection. Confirm a build with
   `PILOT_MAX_OPEN_S` above 300 also fails. Verify the actuator closes at no more
   than 300 seconds and repeated OPEN does not extend the original deadline.
10. Supply simulated battery readings below 3400 mV and above 5000 mV. Verify OPEN
    returns the low/invalid-battery result without pulsing, then verify CLOSE remains
    accepted at both readings.
11. Make OPEN position verification fail. Verify the actuator immediately pulses
    CLOSE and continues retrying if CLOSE is not verified, including with identity
    or radio unavailable. Check physical position.
12. Send cloud `VALVE_ON` and verify no radio OPEN plus a negative cloud ACK. Send
    a unique `VALVE_OFF`, repeat the same ID/node/state tuple, and verify the cached
    ACK without repeated actuation. Reuse that numeric ID with a different node or
    state and verify it is treated as a separate tuple; confirm a delayed old
    completion cannot overwrite the newer result. Inject a fast actuator ACK before
    pending bookkeeping finishes and confirm `COMPLETE` is not changed back to
    `PENDING`. Submit fractional, negative, zero, and out-of-range command/node IDs;
    verify each is rejected before radio transmission and cannot wrap to another node.
    Fill the pending tracker in a harness: verify duplicate live OPEN rejection,
    confirm live OPEN records are never evicted, and confirm only a newer CLOSE can
    replace the oldest CLOSE. Force LoRa TX insertion failure and verify an unused
    reservation is cleared and an oldest CLOSE selected for replacement is restored
    exactly.
13. Remove farm Wi-Fi and cloud access. Verify LoRa control and CSV logging continue,
    then confirm no claim is made that missed cloud records were replayed.
14. Remove power from the actuator while the physical valve is open. Use the manual
    shutoff and document the result; a latching valve cannot close without energy.

Keep the physical shutoff available throughout the pilot even after every item
passes.

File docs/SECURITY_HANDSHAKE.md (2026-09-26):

# Security: physical provisioning and AES-128-GCM

## Provisioning model

There is no over-the-air registration handshake. Each sensor or actuator receives a
role-bound identity over its physical USB serial connection. The gateway receives a
matching record through its authenticated dashboard.

```text
Physical USB console                    Gateway dashboard
--------------------                    -----------------
Generate a unique 16-byte PSK
PROVISION 0001 <32 hex>                 Add node 0x0001
Node stores role + ID + raw PSK         Select matching type
in dev_ident NVS                        Enter the same raw PSK
Radio starts only after validation      Gateway stores node in node_db NVS
```

Use `STATUS` to inspect role, state, ID, and chip identity. The PSK is never printed.
`0000`, `FFFF`, an all-zero key, and an all-`FF` key are rejected.

```text
STATUS
PROVISION 0001 <32-hex-PSK>
UNPROVISION 0001 CONFIRM
ERASE CORRUPT CONFIRM
```

`PROVISION` only works when the identity is empty. `UNPROVISION` requires the
current ID and explicit confirmation. The final command is accepted only for a
corrupt or role-mismatched record. Identity records include a CRC to detect storage
corruption; the CRC is not a secret or an at-rest encryption mechanism.

The gateway refuses duplicate node IDs rather than overwriting a PSK and resetting
replay counters. Reprovisioning requires explicit removal at the gateway,
`UNPROVISION` over the physical node console, and a newly generated PSK. A newly
registered node has no freshness credit; the gateway blocks OPEN until it accepts a
fresh authenticated packet from the physical actuator.

The node and gateway store the raw per-node PSK in NVS. Restrict physical access,
disable debug access for any later production design, and never include PSKs in
logs, tickets, screenshots, or source control.

## Per-packet authenticated encryption

| Parameter | Value |
|---|---|
| Algorithm | AES-128-GCM using mbedTLS |
| Key | Unique 16-byte PSK per field node |
| Nonce/IV | 12 bytes |
| AAD | node ID (2) + packet type (1) + sequence (4) |
| Authentication tag | Full 16 bytes |

The transmitted nonce is:

```text
[packet_type | 0x00 | node_id_hi | node_id_lo | sequence in 8-byte field]
```

The current counter is 32 bits and occupies the low bytes of the nonce's sequence
field. Packet type separates telemetry, command, ACK, and heartbeat nonce spaces.
Node ID and type are also authenticated as AAD with the sequence.

Do not mix this release with older firmware that transmitted a 4-byte tag. All
gateway, sensor, and actuator firmware must be updated together.

## Replay and nonce rules

- Each transmitter reserves sequence ranges in `lora_seq` before using them.
- Gateway replay state is independent for telemetry, heartbeat, and ACK streams.
- The actuator persists the last accepted command sequence.
- Packets at or below the stored sequence for that stream are dropped.
- A stream must stop and receive a new PSK before the 32-bit counter is exhausted.

NVS writes are not assumed successful. Sequence-block reservations and replay
checkpoints are read back before use. A reservation failure suppresses that
transmission; an actuator replay-load failure keeps radio disabled; a replay-save
failure rejects the command before movement; and a gateway replay-save failure
rolls state back and rejects the packet.

Identity removal deliberately does not erase `lora_seq`. Do not restore an old NVS
backup, clone NVS to another board, or clear sequence state while retaining a PSK.
After a full flash erase, NVS replacement, or uncertain sequence history, generate
a fresh PSK and update both node and gateway.

## Cloud and local access

The optional cloud client accepts only an `https://` base URL and requires both an
API key and a PEM CA certificate. It sends the key in `X-API-Key` and validates the
server certificate against the supplied CA. The supervised pilot rejects cloud
`VALVE_ON` with a negative ACK and permits only remote `VALVE_OFF`. Cloud idempotency
uses command ID together with node ID and requested state. Identifiers are validated
before narrowing: `command_id` must be an integer from 1 through `UINT32_MAX`, and
`node_id` must be an integer from 1 through 65534. Negative, zero, non-integer, and
out-of-range values are rejected instead of wrapping to a different identifier. Only
an exact completed tuple returns a cached ACK; a delayed completion with a different
node/state is ignored, and a fast ACK cannot downgrade a completed tuple to pending.
Other pre-radio rejections also produce negative ACKs. This cache is bounded and
volatile, so the server must issue unique command IDs and retain outcomes.

The commissioning AP uses WPA2 and a generated password printed on physical serial.
The farm-network dashboard uses HTTP Basic authentication. Place it on an isolated
pilot network. Browser OTA and local MQTT are disabled by default in the supervised
pilot build.

These controls provide packet confidentiality/integrity, replay rejection, and
basic local/cloud access control. They do not provide signed firmware, secure boot,
flash encryption, hardware key storage, or proof that a physical valve moved.

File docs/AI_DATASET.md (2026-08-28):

# AI Dataset Collection Guide

## Objective

The prototype records trustworthy field observations for training irrigation,
leak/blockage detection and equipment-health models. It does not fabricate a
dataset or run an unvalidated model. First collect real data across different
soil conditions, weather, crop stages and irrigation events.

## Before collection

1. Flash the matching gateway, sensor and actuator builds.
2. Upload the gateway LittleFS dashboard after changing the partition table.
3. Provision each node with its unique ID and PSK.
4. In **AI Dataset**, select each sensor node and enter crop, growth stage,
   soil type, zone area and emitter flow.
5. Measure and save the sensor's dry and saturated/wet raw ADC endpoints.
6. Confirm the actuator dashboard reports **Feedback: verified** before using
   automatic irrigation.
7. If hydraulic sensors are installed, calibrate their constants and explicitly
   enable `ENABLE_HYDRAULIC_SENSORS` before flashing the actuator.

## CSV schema version 3

Each row contains `schema_version`, `record_type`, UTC `epoch_ms`, `uptime_ms`,
`boot_id`, `node_id`, `linked_node_id`, packet `sequence`, raw/calibrated sensor values, weather,
battery and RSSI, commanded/actual valve state, command outcome/source,
hydraulic measurements, error flags, agronomic metadata (including zone area
and emitter flow), human labels, and traceable Edge-AI predictions. AI columns
include the model version, shadow/control state, irrigation probability and
decision, water/runtime schedule, weather forecast, dry-down rate,
watering-effect result and equipment fault score. Actuator rows use `linked_node_id` for the
sensor zone selected in actuator automation configuration.

On first boot after a schema-2 upgrade, the gateway preserves the old current
file as the downloadable previous segment and creates a fresh schema-3 file.
This avoids mixing rows with different column counts.

Record types:

| Type | Meaning |
|---|---|
| `sensor` | Raw ADC, calibrated moisture, soil temperature, node battery and RSSI |
| `weather` | Rain, wind, direction, air temperature, humidity, pressure, light and gateway battery |
| `command` | Requested valve state, source and sequence |
| `command_ack` | Actuator result, actual valve state, feedback validity and errors |
| `actuator` | Periodic actual/commanded state and optional hydraulic telemetry |
| `label` | Farmer/operator observation entered in the dashboard |

Blank measurement fields are written as `nan`; do not replace them with zero.
A zero flow reading is a real observation, while `nan` means the sensor was not
connected or the measurement was unavailable.

## Labels

Add an event marker as soon as a known event happens. Available dashboard labels
include normal observation, irrigation start/end, rain, leak, blocked pipe,
empty tank, sensor fault and valve fault. Use notes for details such as the zone,
maintenance action, measured water quantity or independent reference reading.

Labels are observations, not proof. Review them before training and keep a log
of how each label was established.

## Retention and export

The gateway keeps two rolling 1.25 MiB segments:

- `/api/dataset/export` downloads the current segment.
- `/api/dataset/export?archive=1` downloads the previous segment.

Both routes require dashboard authentication. When the current segment fills,
the previous segment is replaced. Download both files regularly and merge them
off-device, or configure HTTPS cloud ingestion. Local storage is an outage
buffer, not a multi-week data warehouse.

Do not clear the dataset until both segments have been backed up and opened
successfully. The dashboard clear action deletes both local segments.

## Minimum collection campaign

Collect at least four to eight weeks spanning dry-down, irrigation and rainfall,
with multiple representative zones. Record independent soil-moisture reference
measurements and actual water volumes when possible. Intentionally document
safe fault tests such as a closed supply or disconnected sensor; never create a
real leak solely to generate data.

## Model deployment gate

1. Join rows by time and the configured sensor-to-actuator zone relationship.
2. Split training, validation and test data by date or field, not random rows,
   to reduce leakage from adjacent time samples.
3. Report false-negative rates for leak, blockage and dry-soil events.
4. Convert and test the selected small model on the ESP32-S3.
5. Run it in **shadow mode**: log recommendations but do not actuate.
6. Compare recommendations with farmer decisions and existing threshold rules.
7. Permit control only after field acceptance tests; retain maximum runtime,
   valve feedback and hydraulic fail-safes outside the AI model.

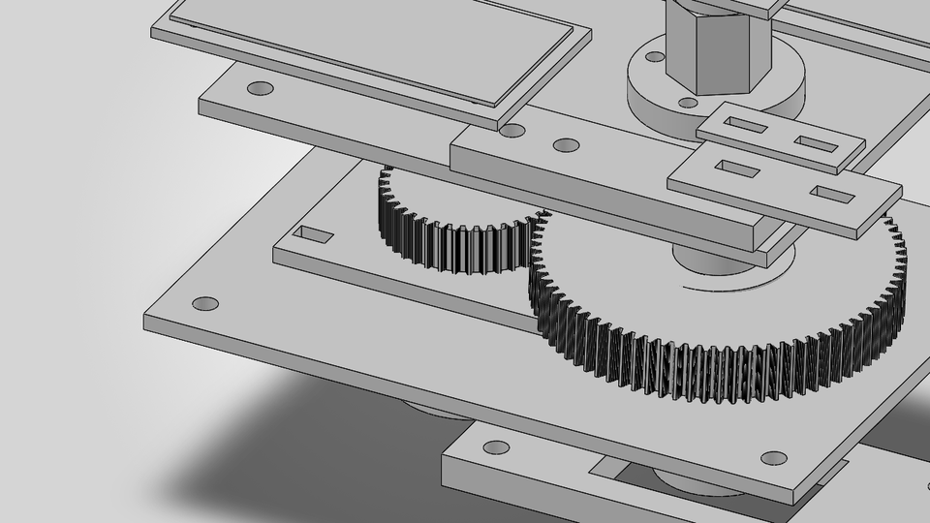
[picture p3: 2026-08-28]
hardware/actuator/cad/motion/AMR_Valve_Open_Close_Poster.png

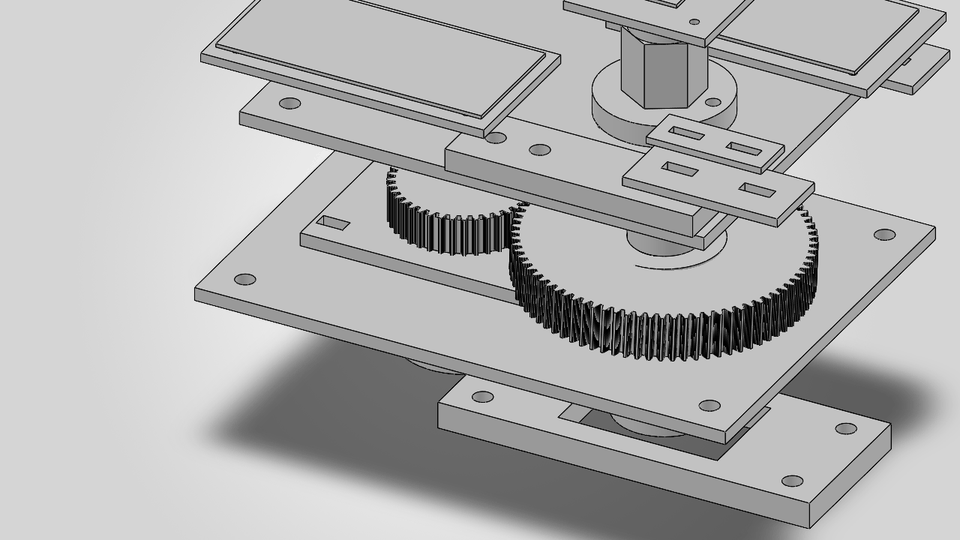
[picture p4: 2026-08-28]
hardware/actuator/cad/motion/AMR_Valve_Open_Close.gif

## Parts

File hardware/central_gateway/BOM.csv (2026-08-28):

Reference | Value | Description | Manufacturer Part Number | Footprint | Quantity
U1 | ESP32-S3-DevKitC-1-N8R8 | Espressif ESP32-S3 development board | ESP32-S3-DEVKITC-1-N8R8 | AMR_Central_ESP32-S3-DevKitC-1_Carrier | 1
U2 | RFM95W-868S2 | HopeRF 868/915MHz LoRa module | RFM95W-868S2 | AMR_Central_HOPERF_RFM95W_SMD | 1
U3 | R-78E5.0-1.0 | 1A 5V SIP switching regulator | R-78E5.0-1.0 | AMR_Central_RECOM_R-78E5.0-1.0_SIP3 | 1
U4 | AP2112K-3.3 | 600mA low-noise 3.3V LDO | AP2112K-3.3TRG1 | AMR_Central_SOT-23-5 | 1
J1,J6,J7 | 2-pin 5.08mm terminal block | Pluggable or fixed terminal block | Generic | AMR_Central_TerminalBlock_2 | 3
J2,J3 | 615006138421 | Horizontal six-position RJ11-compatible modular jack, tab up | Wuerth Elektronik 615006138421 | AMR_Central_WR-MJ_615006138421 | 2
J4 | 3-pin 5.08mm terminal block | Pluggable or fixed terminal block | Generic | AMR_Central_TerminalBlock_3 | 1
J5 | 4-pin 5.08mm terminal block | Pluggable or fixed terminal block | Generic | AMR_Central_TerminalBlock_4 | 1
J8 | 1x4 2.54mm header | Service UART header | Generic | AMR_Central_Header_1x4 | 1
J9 | SMA female vertical | 868MHz antenna connector | Generic | AMR_Central_SMA_Vertical_THT | 1
J10 | B2B-XH-A(LF)(SN) | 2-pin 2.50mm locking header for enclosure button harness | JST B2B-XH-A(LF)(SN) | AMR_Central_JST_XH_B2B-XH-A_1x02_P2.50mm | 1
ENC-SW1 | Panel momentary NO button | Enclosure-mounted setup/reset button wired to J10 | Select for enclosure/IP rating | OFF_BOARD | 1
F1 | PTC 0.75A | 1812 resettable fuse | MF-MSMF075-2 | AMR_Central_Fuse_1812 | 1
D1 | SMBJ18A | 600W unidirectional TVS | SMBJ18A | AMR_Central_D_SMB | 1
D2 | SS34 | 3A 40V Schottky diode | SS34 | AMR_Central_D_SMA | 1
D3-D9 | PESD3V3 | 3.3V ESD protection diode | PESD3V3U1BA | AMR_Central_D_SOD323 | 7
D10 | BZT52C6V2 | 6.2V Zener clamp | BZT52C6V2 | AMR_Central_D_SOD323 | 1
LED1 | GREEN | 0805 green LED | Generic | AMR_Central_LED_0805 | 1
R1,R2,R4,R12,R14 | 1k | 0805 1% resistor | Generic | AMR_Central_R_0805 | 5
R3,R5,R13,R15 | 10k | 0805 1% resistor | Generic | AMR_Central_R_0805 | 4
R6 | 220R | 0805 1% resistor | Generic | AMR_Central_R_0805 | 1
R7,R10,R11 | 4.7k | 0805 1% resistor | Generic | AMR_Central_R_0805 | 3
R8,R9 | 100R | 0805 1% resistor | Generic | AMR_Central_R_0805 | 2
R16,R17 | 100k 1% | 0805 precision divider | Generic | AMR_Central_R_0805 | 2
C1 | 10uF 35V | 1210 X7R input capacitor | Generic | AMR_Central_C_1210 | 1
C2 | 22uF 10V | 1206 X7R output capacitor | Generic | AMR_Central_C_1206 | 1
C3,C4 | 1uF | 0805 X7R capacitor | Generic | AMR_Central_C_0805 | 2
C5 | 10uF | 0805 X7R LoRa bulk capacitor | Generic | AMR_Central_C_0805 | 1
C6,C11 | 100nF | 0805 X7R capacitor | Generic | AMR_Central_C_0805 | 2
TP1-TP4 | Test points | Through-hole loop/test point | Generic | AMR_Central_TestPoint_THT | 4

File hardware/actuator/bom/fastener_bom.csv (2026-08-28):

Item | Description | Qty | Use
F01 | M3 x 8 A4 socket screw | 12 | Electronics and sensor PCBs
F02 | M3 A4 Nyloc + washer | 12 | Electronics
F03 | M4 x 12 A4 socket screw | 8 | Sensor/reed brackets
F04 | M4 A4 Nyloc + washer | 8 | Sensor/reed brackets
F05 | M5 x 16 A4 socket screw | 8 | Microswitch and small structure
F06 | M5 A4 Nyloc + washer | 8 | Small structure
F07 | M6 x 20 A4 socket screw | 16 | Motor, carriers, shaft flange
F08 | M6 A4 Nyloc + washer | 16 | Motor, carriers, shaft flange
F09 | M8 x 70 A4 bolt | 4 | Valve bridge clamp; confirm length
F10 | M8 A4 Nyloc + large washer | 4 | Valve bridge clamp
F11 | M8 x 35 steel stop screw | 2 | Mechanical stops
F12 | M8 jam nut | 4 | Two per stop
F13 | M16 prevailing-torque nut | 1 | Clutch preload
F14 | M16 Belleville washers | 1 | Select stack for about 530 N initial preload
F15 | 6 x 6 mm parallel key | 1 | Output hub; length per hub
F16 | 5 mm stainless cross-pin | 1 | Manual override
F17 | 47 mm internal bearing retainer | 4 | Two per bearing carrier or drawing-equivalent plates
F18 | M4 A4 enclosure screw | 12 | Gasketed cover; captive preferred

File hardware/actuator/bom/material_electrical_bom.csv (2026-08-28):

Item | Description | Qty | Specification | Release note
M01 | 5840-31ZY double-shaft gearmotor | 1 | 12 V, 40 rpm nominal | HOLD - measure supplier unit
M02 | 6204-2RS sealed bearing | 2 | 20 x 47 x 14 mm | Known standard
M03 | AS5600 angle module | 1 | 3.3 V I2C | Measure PCB and magnet gap
M04 | Diametric magnet | 1 | 6 x 2.5 mm target | Match AS5600 vendor guidance
M05 | Reed switch | 2 | Sealed dry contact | OPEN/CLOSED confirmation
M06 | Reed cam magnet | 2 | Small NdFeB, retained | Pot and mechanically capture
M07 | Long-lever microswitch | 2 | C/NO/NC, 250 VAC 5 A | Used at low-current control level
M08 | Manual interlock switch | 1 | Two-pole NC + auxiliary | Hardware driver disable
M09 | TTGO LoRa32 v2.1 | 1 | 868 MHz | Antenna separated from motor
M10 | BTS7960 / IBT-2 | 1 | High-current H bridge | Qualify against measured stall current
M11 | MCP23017 input expander | 1 | 3.3 V I2C | Reeds, limits, manual input
M12 | 3S BMS | 1 | Balancing + overcurrent | Rating from measured current
M13 | Protected 18650 cell | 3 | Matched cells, 3S1P | 12.6 V maximum
M14 | Fuse and holder | 1 | DC rated | Size after motor-current test
M15 | Logic DC/DC converter | 1 | 12.6 V input to stable logic rail | Automotive/transient capable
M16 | EPDM clamp liner | 1 | 3 mm sheet | Protect PVC body
M17 | EPDM enclosure gasket | 1 | Closed-cell | Compression verified by ingress test
M18 | Cable glands | 4 | IP68, sized to cables | Strain relief
M19 | Hydrophobic vent | 1 | IP67 pressure equalization | Above drainage plane
M20 | Friction washers | 2 | Oil/water-stable friction material | Torque test wet and dry
M21 | Bronze/steel gear sleeve | 1 | 30.0 mm nominal interface | Final tolerance after wear test

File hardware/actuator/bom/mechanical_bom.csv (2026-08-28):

Item | Description | Qty | Material | Process | Critical note
P01 | Lower base plate | 1 | 6061-T6 | Laser/CNC + anodize | 240 x 180 x 6 mm
P02 | Upper support plate | 1 | 6061-T6 | Laser/CNC + anodize | 210 x 160 x 6 mm
P03 | Adjustable motor bracket | 1 | 6061-T6 | Laser/CNC + anodize | +/-5 mm mesh adjustment
P04 | 40T motor gear | 1 | PA12-CF | FDM + metal D insert | m1.5, PA20, 17 mm face
P05 | 80T clutch gear | 1 | PA12-CF | FDM + face finish | m1.5, PA20, 20 mm face
P06 | 20 mm output shaft/flange | 1 | 4140 or 316 SS | Turn/mill/grind | 20 h6 journals; 4 x M6 flange
P07 | Output gear clutch hub | 1 | C45 steel | Turn/keyway/zinc | OD50, bore20.1
P08 | Clutch pressure plate | 1 | C45 steel | Turn/grind/zinc | OD62, bore17.2, t5
P09 | Belleville stack | 1 | Spring steel | Purchased/calibrated | Initial preload about 530 N
P10 | Replaceable stem adapter | 1 | 17-4PH or PA12-CF | Machine/print | 44 x 18; stem HOLD
P11 | 50 mm valve bridge clamp | 1 | 6061-T6 | CNC + anodize | 72 mm HOLD opening
P12 | 63 mm alternative clamp | 1 | 6061-T6 | CNC + anodize | 88 mm HOLD opening; alternative
P13 | AS5600 bracket | 1 | 6061 or PA12-CF | Machine/print | Nonmagnetic, adjustable
P14 | Magnet carrier | 1 | PA12-CF | FDM | Final shaft mounting
P15 | Reed cam ring | 1 | PA12-CF | FDM | Two adjustable magnets
P16 | OPEN reed bracket | 1 | 316 SS | Laser | Slotted
P17 | CLOSED reed bracket | 1 | 316 SS | Laser | Slotted
P18 | OPEN microswitch bracket | 1 | 316 SS | Laser | +/-5 deg adjustment
P19 | CLOSED microswitch bracket | 1 | 316 SS | Laser | +/-5 deg adjustment
P20 | Mechanical stop bracket | 1 | 6061 or steel | Machine | Two M8 stops
P21 | 3S1P battery tray | 1 | ASA/PA12-CF | FDM | 3 x protected 18650 envelope
P22 | TTGO tray | 1 | ASA/PA12-CF | FDM | USB service access
P23 | BTS7960 tray | 1 | ASA/PA12-CF | FDM | 25 mm heatsink clearance
P24 | Manual override hex | 1 | 316 SS | Turn/mill/passivate | 30 AF, bore20.2, cross-pin
P25 | Gasketed enclosure cover | 1 | UV PC/ASA | FDM/mould | IP65/IP67 design intent
P26 | Lower bearing carrier | 1 | 6061-T6 | Turn/mill/anodize | 47 H7 x 16; retainers
P27 | Upper bearing carrier | 1 | 6061-T6 | Turn/mill/anodize | 47 H7 x 16; retainers

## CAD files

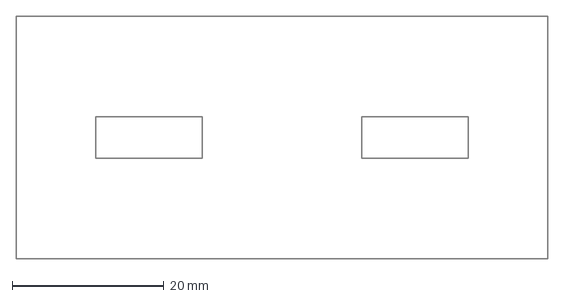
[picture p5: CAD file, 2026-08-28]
hardware/actuator/cad/dxf/Microswitch_Bracket_OPEN.dxf
70.0 x 32.0 mm

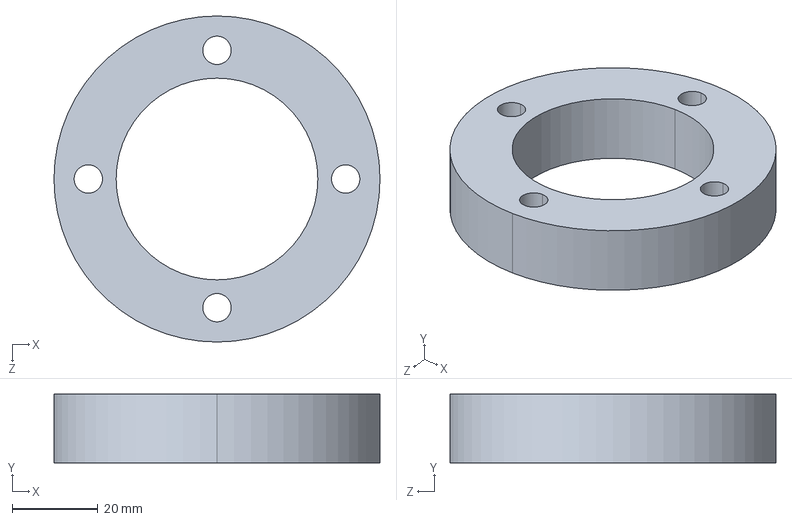
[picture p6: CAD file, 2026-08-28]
hardware/actuator/cad/step/26_Lower_Bearing_Carrier.STEP
76.0 x 16.0 x 76.0 mm

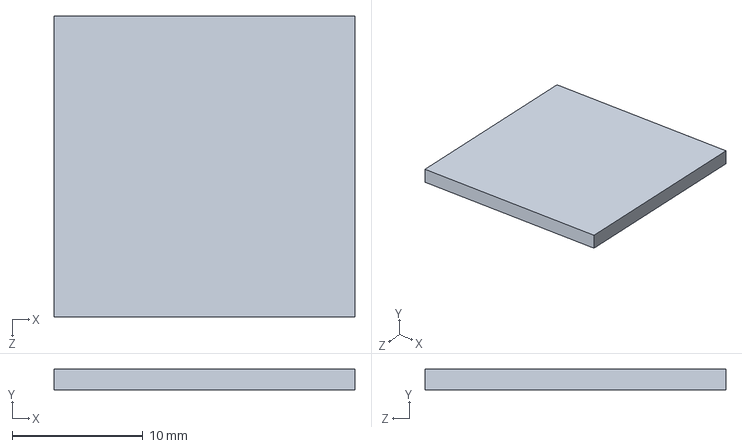
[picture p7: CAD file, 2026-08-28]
hardware/actuator/cad/step/REF_AS5600_PCB.STEP
23.0 x 1.60 x 23.0 mm

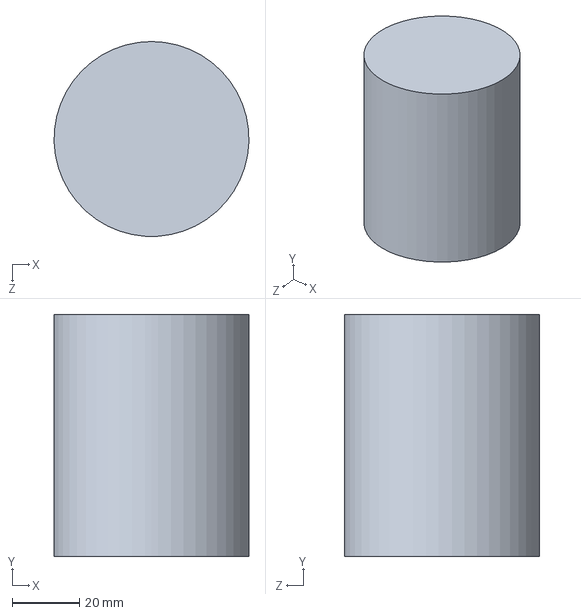
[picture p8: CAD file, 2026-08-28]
hardware/actuator/cad/native/REF_5840_31ZY_Motor.SLDPRT
58.0 x 72.0 x 58.0 mm

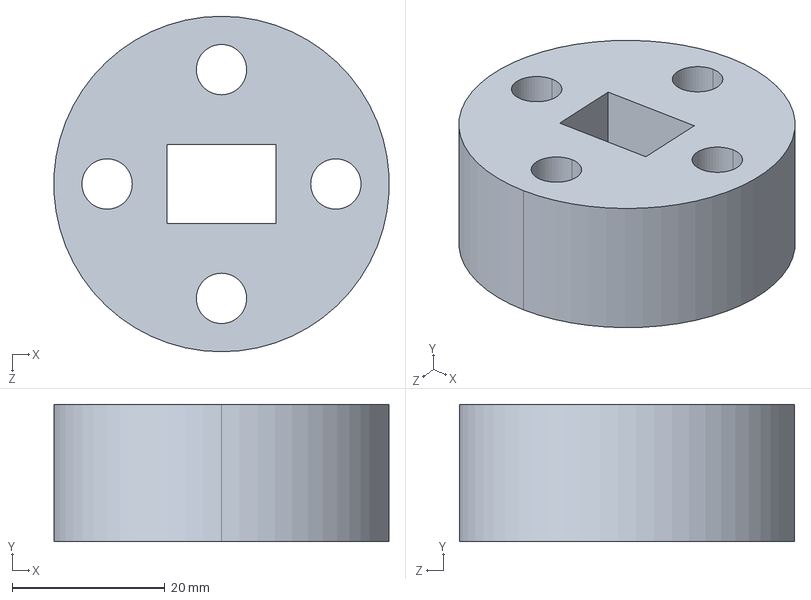
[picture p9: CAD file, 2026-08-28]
hardware/actuator/cad/step/10_Valve_Stem_Adapter.STEP
43.9 x 18.0 x 44.0 mm

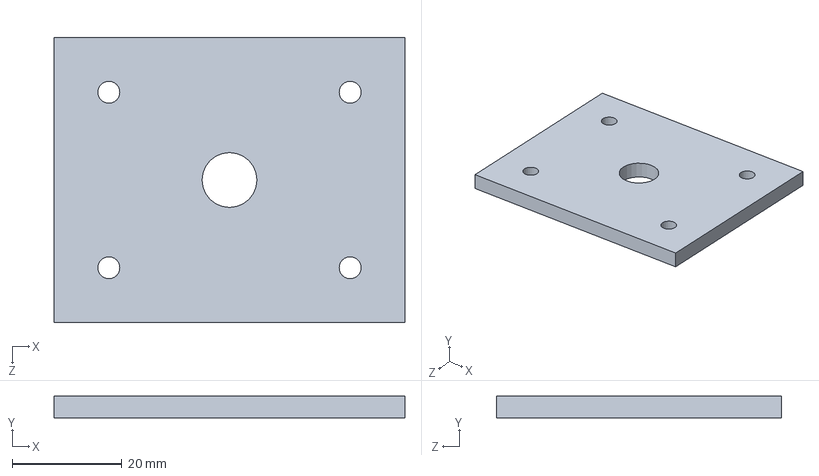
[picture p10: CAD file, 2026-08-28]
hardware/actuator/cad/native/13_AS5600_Bracket.SLDPRT
64.0 x 4.00 x 52.0 mm

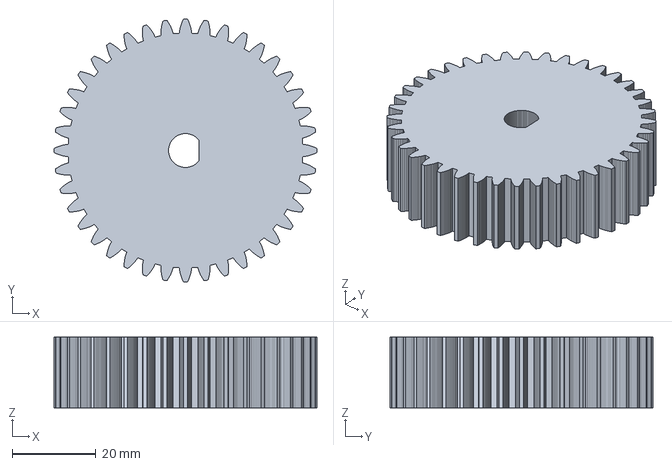
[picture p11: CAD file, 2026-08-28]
hardware/actuator/cad/step/04_Motor_Gear_40T.STEP
63.0 x 63.0 x 17.0 mm

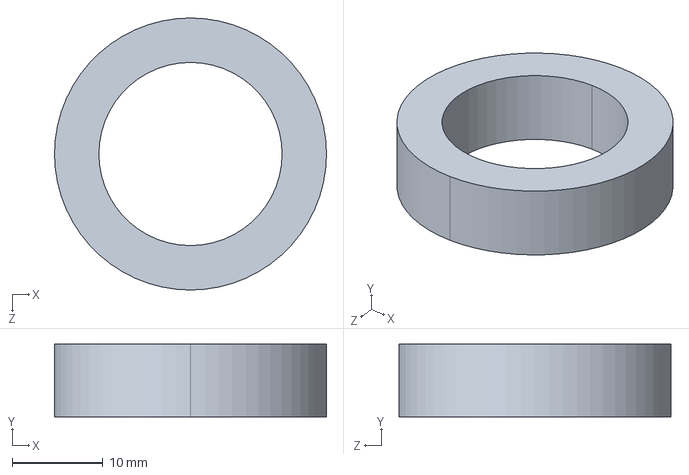
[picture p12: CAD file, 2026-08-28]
hardware/actuator/cad/step/14_Magnet_Carrier.STEP
30.0 x 8.00 x 30.0 mm

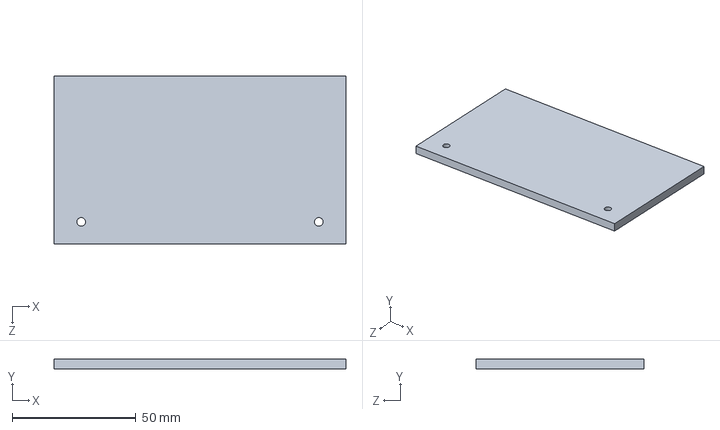
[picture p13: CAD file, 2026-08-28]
hardware/actuator/cad/native/23_Motor_Driver_Tray.SLDPRT
118.0 x 4.00 x 68.0 mm

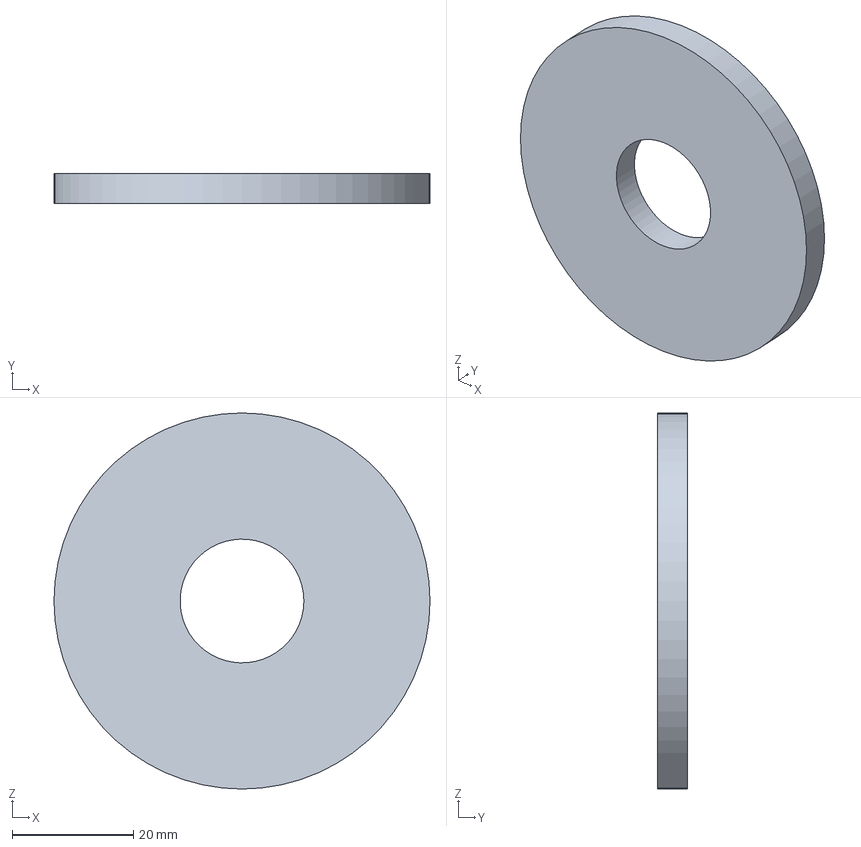
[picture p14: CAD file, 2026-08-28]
hardware/actuator/cad/step/08_Clutch_Pressure_Plate.STEP
62.0 x 5.00 x 62.0 mm

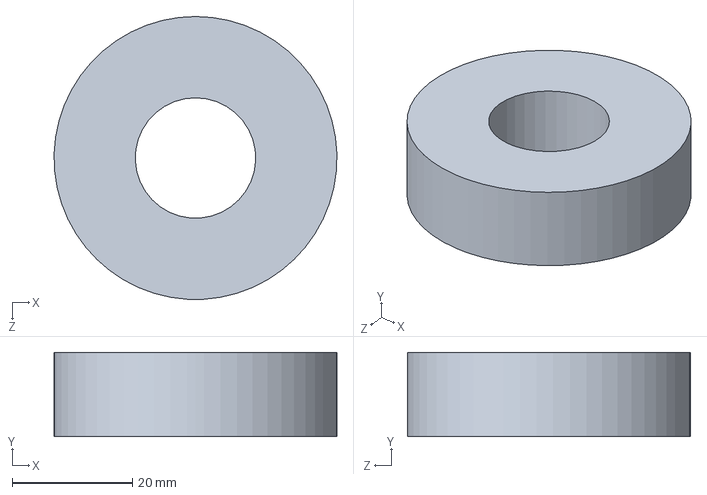
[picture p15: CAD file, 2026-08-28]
hardware/actuator/cad/native/REF_6204_2RS_Bearing.SLDPRT
47.0 x 14.0 x 47.0 mm

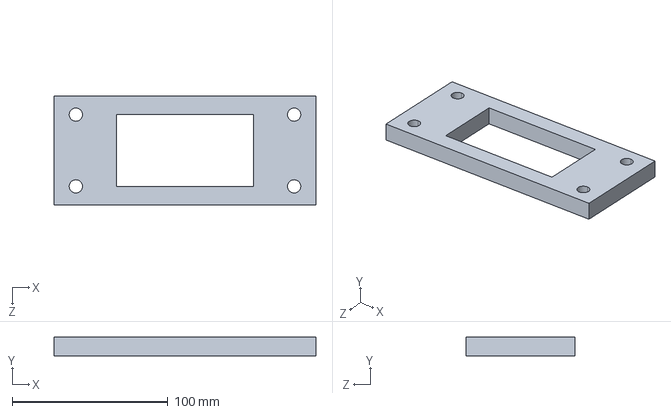
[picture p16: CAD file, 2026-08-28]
hardware/actuator/cad/step/12_Valve_Clamp_63mm.STEP
168.0 x 12.0 x 70.0 mm

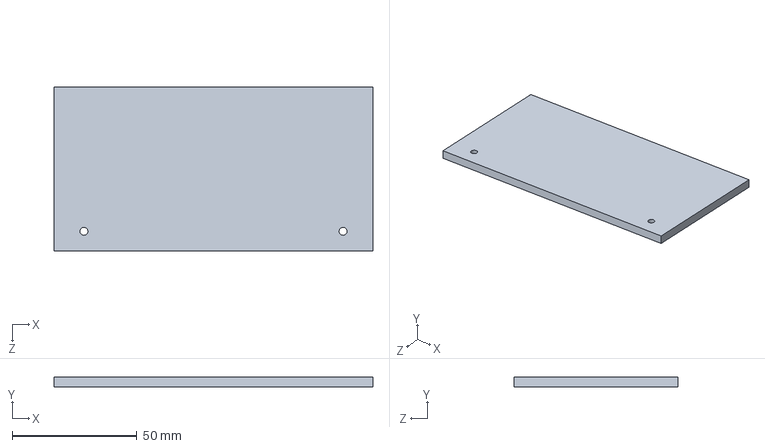
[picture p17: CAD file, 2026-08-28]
hardware/actuator/cad/native/22_TTGO_Tray.SLDPRT
128.0 x 4.00 x 66.0 mm

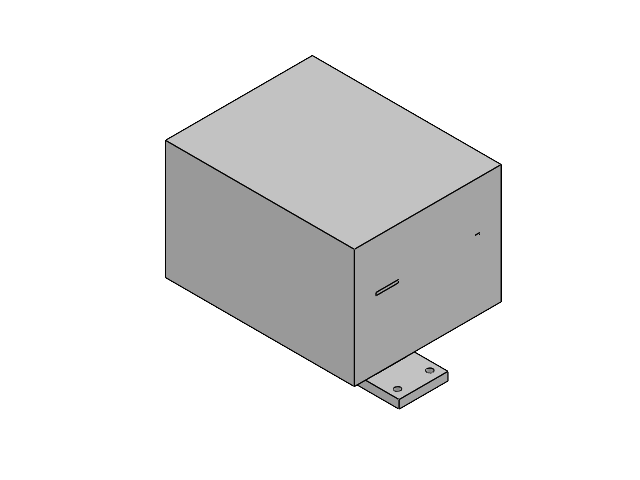
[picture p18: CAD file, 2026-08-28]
hardware/actuator/cad/native/AMR_50mm_Valve_Actuator.SLDASM
01_Lower_Base_Plate
02_Upper_Support_Plate
03_Motor_Bracket
04_Motor_Gear_40T
05_Output_Gear_80T
06_Output_Shaft
07_Output_Gear_Hub
08_Clutch_Pressure_Plate
09_Belleville_Stack_Reference
10_Valve_Stem_Adapter
11_Valve_Clamp_50mm
13_AS5600_Bracket
14_Magnet_Carrier
15_Reed_Switch_Cam
16_Reed_Bracket_OPEN
17_Reed_Bracket_CLOSED
18_Microswitch_Bracket_OPEN
19_Microswitch_Bracket_CLOSED
20_Mechanical_Stop_Bracket
21_Battery_Tray
22_TTGO_Tray
23_Motor_Driver_Tray
24_Manual_Override
25_Gear_Enclosure_Cover
26_Lower_Bearing_Carrier
27_Upper_Bearing_Carrier
REF_6204_2RS_Bearing x 2
REF_5840_31ZY_Motor
REF_AS5600_PCB
REF_TTGO_LORA32
REF_BTS7960_IBT2
REF_18650_Cell x 3

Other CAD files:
hardware/actuator/cad/native/AMR_50mm_Valve_Actuator_RESOLVED.SLDASM
hardware/actuator/cad/dxf/01_Lower_Base_Plate.dxf
hardware/actuator/cad/dxf/02_Upper_Support_Plate.dxf
hardware/actuator/cad/dxf/03_Motor_Bracket.dxf
hardware/actuator/cad/dxf/11_Valve_Clamp_50mm.dxf
hardware/actuator/cad/dxf/12_Valve_Clamp_63mm.dxf
hardware/actuator/cad/dxf/13_AS5600_Bracket.dxf
hardware/actuator/cad/dxf/20_Mechanical_Stop_Bracket.dxf
hardware/actuator/cad/native/01_Lower_Base_Plate.SLDPRT
hardware/actuator/cad/native/02_Upper_Support_Plate.SLDPRT
hardware/actuator/cad/native/03_Motor_Bracket.SLDPRT
hardware/actuator/cad/native/04_Motor_Gear_40T.SLDPRT
hardware/actuator/cad/native/05_Output_Gear_80T.SLDPRT
hardware/actuator/cad/native/06_Output_Shaft.SLDPRT
hardware/actuator/cad/native/08_Clutch_Pressure_Plate.SLDPRT
hardware/actuator/cad/native/09_Belleville_Stack_Reference.SLDPRT
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

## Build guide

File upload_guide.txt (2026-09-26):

AMR FIRMWARE UPLOAD GUIDE
=========================

Install PlatformIO, connect the target board by USB, and identify its COM port.
The tested build pins Espressif32 platform 7.0.1 and exact library versions in
platformio.ini. Do not replace them with floating/latest constraints for the pilot.

1. ESP32-S3 CENTRAL GATEWAY
----------------------------
Firmware:
  pio run -e central_gateway -t upload --upload-port COM_PORT

Dashboard filesystem:
  pio run -e central_gateway -t uploadfs --upload-port COM_PORT

Windows helper (defaults to COM4):
  flash_central.bat COM_PORT

Serial monitor:
  pio device monitor --port COM_PORT --baud 115200

Upload gateway firmware before the filesystem. If connection fails, hold BOOT while the upload starts.
The gateway uses a custom 8 MB partition map. On the first installation of this
release, both commands are mandatory; do not upload only the filesystem.

2. SOIL SENSOR NODE
-------------------
  pio run -e sensor_node -t upload --upload-port COM_PORT
  pio device monitor --port COM_PORT --baud 115200

Provision over the physical serial monitor (replace the example ID and PSK):
  STATUS
  PROVISION 0001 <32_HEX_SENSOR_PSK>

3. ACTUATOR NODE
----------------
  pio run -e actuator_node -t upload --upload-port COM_PORT
  pio device monitor --port COM_PORT --baud 115200

Provision over the physical serial monitor using a different ID and PSK:
  STATUS
  PROVISION 0002 <32_HEX_ACTUATOR_PSK>

IMPORTANT
---------
- Flash matching releases to the gateway, sensor and actuator. This release uses
  a full 16-byte radio authentication tag and is incompatible with the old 4-byte tag.
- The gateway commissioning AP is WPA2 protected. Read its generated password
  from the gateway's physical 115200-baud serial console.
- Create the dashboard administrator password on the setup page.
- Add the exact same node ID, type and unique PSK to the gateway dashboard.
- The gateway refuses duplicate node IDs. Remove the old gateway record and
  unprovision the physical node before reprovisioning, then generate a new PSK.
- Wait for a fresh authenticated node packet after gateway provisioning before
  testing commands; registration alone never marks a node online.
- Generate a new PSK after any full node NVS erase. Do not reuse a PSK after
  sequence state was cleared, and do not clone NVS between devices.
- Check serial logs after first boot. A replay/sequence NVS readback failure keeps
  the actuator radio disabled or rejects traffic; do not pilot a node reporting it.
- Browser OTA is disabled in the supervised pilot; update by physical USB.
- Never publish node PSKs, administrator passwords or cloud API keys.
- See docs/PILOT_DEPLOYMENT.md before connecting a valve to water.

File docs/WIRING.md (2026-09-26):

# Wiring Diagram

## 1. Central Gateway — ESP32-S3 + RFM95W

```
RFM95W (SX1276):
  RST  ── GPIO 14
  NSS  ── GPIO 18
  SCK  ── GPIO 12
  MOSI ── GPIO 11
  MISO ── GPIO 13
  DIO0 ── GPIO 2
  DIO1 ── NC

SPI bus (shared):
  SCK  → 12
  MISO → 13
  MOSI → 11
  CS   → 18

Power:
  RFM95W VCC  → 3.3V
  RFM95W GND  → GND

Weather station:
  Rain gauge pulse  ── GPIO 6
  Anemometer pulse  ── GPIO 3
  Wind vane analog ── GPIO 10
  DHT11 data        ── GPIO 7
  LDR analog        ── GPIO 9
  Battery divider   ── GPIO 8
  BMP280 SDA        ── GPIO 4
  BMP280 SCL        ── GPIO 5
```

Central PCB connector map (`hardware/central_gateway`, revision v1.1):

| Connector | Connection |
|---|---|
| J2 rain RJ11 | pins 1/2/5/6 NC, pin 3 GND, pin 4 rain signal |
| J3 wind RJ11 | pin 1/6 NC, pin 2 vane, pin 3 GND, pin 4 wind-speed switch, pin 5 GND |
| J4 DHT screw terminal | 3.3 V, data, GND |
| J5 BMP280 screw terminal | 3.3 V, SDA, SCL, GND |
| J6 LDR screw terminal | LDR signal, GND |
| J9 SMA | RFM95W 868 MHz antenna |
| J10 locking 2-pin | enclosure-mounted normally-open setup/reset button |

The RFM95W LoRa module is soldered directly to the PCB; do not extend its SPI
bus through a screw terminal. J2/J3 numbering is the PCB contact numbering, so
continuity-test the supplied modular cables rather than relying on wire colors.
There is no reset switch on the PCB: holding the enclosure button connected to
J10 for five seconds requests Wi-Fi configuration reset.

The pin map above is the authoritative map compiled in
`src/central/main.cpp`. Do not use earlier TTGO gateway diagrams for the
ESP32-S3 central device.

## 2. Sensor Node — TTGO LoRa32 v2.1

```
Onboard LoRa (SX1276) — no external wiring needed.

Capacitive moisture sensor:
  VCC ── 3.3V
  GND ── GND
  SIG ── GPIO 34 (ADC)

DS18B20 temperature:
  VCC ── 3.3V (with 4.7kΩ pull-up to data)
  GND ── GND
  DAT ── GPIO 4

Battery (single Li-ion 18650):
  BAT+ ── GPIO 35 (via voltage divider, see below)
  BAT- ── GND

  Voltage divider (onboard TTGO):
    R1 = 100kΩ (BAT+ ── GPIO 35)
    R2 = 100kΩ (GPIO 35 ── GND)
    Formula: V_bat = ADC_voltage * 2.0
```

## 3. Actuator Node — TTGO LoRa32 v2.1 + TB6612FNG + Latching Valve

```
Onboard LoRa — same as sensor.

TB6612FNG Motor Driver:
  ┌──────────────────────────────────────┐
  │  TB6612FNG     │  GPIO / Connection  │
  ├────────────────┼──────────────────────┤
  │ AIN1           │  GPIO 2             │
  │ AIN2           │  GPIO 4             │
  │ PWMA           │  GPIO 12            │
  │ STBY           │  GPIO 17            │
  │ VMOT           │  Battery + (4.5-6V) │
  │ VCC            │  3.3V               │
  │ GND            │  GND                │
  │ A01, A02       │  Latching valve     │
  └──────────────────────────────────────┘

Latching electrovane:
  Red  wire ── TB6612 A01
  Blue wire ── TB6612 A02
  (Polarity reversed for open/close via 30ms pulse)

Valve-open feedback (required for verified control and AI labels):
  Dry-contact signal ── GPIO 3 (INPUT_PULLUP)
  Contact CLOSED to GND means valve OPEN.
  Contact OPEN means valve CLOSED.

  The default actuator build disables this input and is manual-only. After wiring
  and dry-bench verification, add `-DACTUATOR_VALVE_FB_PIN=3` to the actuator build
  flags to enable measured feedback.

Battery (single Li-ion 18650):
  BAT+ ── GPIO 35 (same divider as sensor: 100k+100k)
  BAT- ── GND

  Note: TB6612 VMOT is also powered from battery (4.5-6V range).
  Use a boost converter if battery voltage drops below 4.5V.
```

### Optional hydraulic sensors on the actuator node

These inputs are compiled but disabled by default so unconnected pins cannot
produce false data:

```
Flow meter pulse       ── GPIO 13
Pressure analog        ── GPIO 34
Tank-level analog      ── GPIO 36
Pump-current analog    ── GPIO 37
```

After the signal-conditioning circuits and sensors are connected, add
`-DENABLE_HYDRAULIC_SENSORS=1` to the `actuator_node` build flags in
`platformio.ini`. Adjust `FLOW_PULSES_PER_LITER`, pressure full scale, tank
calibration, and current-sensor full scale in `src/actuator/main.cpp` to match
the actual sensor datasheets. Analog inputs must never exceed 3.3 V.

GPIO 23 is reserved for the TTGO board's onboard SX1276 reset. GPIO 26 is
the LoRa interrupt, and GPIO 32/33 are the LoRa DIO2/DIO1 signals; do not use
those pins for the valve driver or hydraulic sensors.

## 4. Battery Voltage Divider (all nodes)

```
All nodes use GPIO 35 for battery measurement with the onboard TTGO
voltage divider (or external if using bare ESP32):

      BAT+ (3.7-4.2V)
           │
          ┌┴┐
          │ │ R1 = 100kΩ
          └┬┘
           ├──── GPIO 35 (ADC)
          ┌┴┐
          │ │ R2 = 100kΩ
          └┬┘
           │
          GND

Division ratio: V_GPIO35 = V_bat * R2 / (R1 + R2) = V_bat / 2

ADC formula in code:
  V_bat = (analogRead(35) / 4095.0) * 3.3 * 2.0

Pilot actuator OPEN gate:
  OPEN is rejected below 3.4 V or above an implausible 5.0 V reading.
  CLOSE remains allowed. Validate the divider against a calibrated meter before
  relying on this gate; a wrong divider ratio can produce a misleading reading.

For TTGO boards, the divider is pre-soldered (R1=100k, R2=100k).
For bare ESP32-S3, add external 100k+100k divider.
```

## 5. LoRa Antenna

```
All nodes:
  Use a 1/4-wave whip antenna tuned for 868 MHz (~8.6 cm).
  SMA or u.FL connector depending on board variant.
  Place antennas at least 30cm apart during testing.
```

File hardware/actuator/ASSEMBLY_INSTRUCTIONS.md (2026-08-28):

# Assembly Instructions

## 1. Preparation

Deburr every metal part. Mask bearing seats and friction faces before surface treatment. Clean printed gears, remove stringing between teeth, and verify the 90.00 mm centre distance on the real plates. Do not force bearings into an undersize printed or anodized bore.

Record the actual motor shaft diameter, D-flat, shaft projection, body diameter, body length, and mounting holes. Record the valve neck/body dimensions, stem profile, stem height, and breakaway torque in both directions before machining the final bracket or adapter.

## 2. Bearing and shaft stack

1. Machine each aluminium carrier to a 47 H7 bearing bore after anodizing allowance is considered.
2. Add the drawing-specified internal retaining grooves or retaining plates.
3. Press or slip-fit one 6204-2RS into each carrier using force only on the outer race.
4. Bolt the lower carrier above the lower plate and the upper carrier below the upper plate.
5. Pass the 20 h6 shaft through both bearings. Confirm free rotation and 1-2 mm valve-stem axial clearance.
6. Bolt the measured stem adapter to the shaft flange with four M6 fasteners and mechanical locking.

Rev-B stack heights from the lower-plate top face are: lower carrier Z=6-22 mm, clutch hub Z=22-48 mm, output gear Z=28-48 mm, pressure plate Z=48-53 mm, Belleville stack Z=53-65 mm, upper carrier Z=65-81 mm, and upper plate Z=81-87 mm. Do not compress this stack by moving the upper carrier into the clutch components.

## 3. Gear and clutch stack

1. Fit a metal D-insert to the 40T motor gear. Do not depend on a printed bore and set screw alone.
2. Fit the metal sleeve/bush in the 80T gear.
3. Assemble the output clutch from bottom to top: keyed output hub, lower friction washer, 80T gear, upper friction washer, steel pressure plate, Belleville stack, M16 prevailing-torque locknut.
4. Set the gear centres to 90.00 mm. Use the motor slots to establish 0.25-0.35 mm practical backlash without tight spots through a full revolution.
5. Phase the 80T gear by one-half tooth pitch (2.25 degrees) relative to the zero-angle 40T gear before checking mesh.
6. Apply plastic-compatible PTFE grease sparingly to the teeth. Keep grease away from clutch friction surfaces.
7. Start clutch calibration at 8 N m. Final setting is 1.5 times measured wet breakaway torque only if that value remains below the verified safe limit of the valve stem, gears, shaft flange, and gearbox.

## 4. Limits and feedback

1. Install the AS5600 on a nonmagnetic bracket directly above the final output shaft.
2. Centre a diametrically magnetized magnet on the shaft and set the module manufacturer's air gap.
3. Calibrate CLOSED and OPEN angles from the real valve, not from motor turns.
4. Set reeds to confirm approximately 2 and 88 degrees.
5. Set normally-closed hard limits near 0 and 90 degrees with at least +/-5 degrees bracket adjustment.
6. Set M8 steel stops at approximately -1 and 91 degrees. Verify the stop block, not the PVC pipe, absorbs reaction torque.
7. Confirm the protection order: AS5600 target, reed, hard limit, steel stop, clutch slip.

## 5. Manual override

Cross-pin or key the 30 mm external-hex override to the final shaft. The manual-mode control must remove BTS7960 enable power through a normally-closed hardware interlock before the tool or handle can engage. The firmware must also report manual mode.

## 6. Valve clamp

Fit a 3 mm EPDM liner between the two bridge supports and the valve body/neck. Tighten four stainless M8 clamp bolts evenly. Do not clamp thin pipe spans or distort the PVC valve body. The 63 mm conversion changes the lower clamp and measured stem adapter only.

## 7. Electronics and enclosure

Keep the battery, TTGO board, BMS, fuse, and motor driver isolated from moving gears. Route motor wires separately from I2C and sensor wires. Place the antenna away from the motor, shaft, and steel fasteners. Use strain-relieved cable glands, a gasketed cover, a hydrophobic pressure vent, and a drainage path outside the sealed electronics chamber.

Install the three 18650 cells horizontally on the battery tray; do not stand them vertically inside the gear cover. The enclosure is installed open-side down with its roof at Z=164-170 mm.

## 8. Commissioning tests

1. Bench test with the valve removed and a current-limited supply.
2. Confirm both hard limits interrupt motion in the hazardous direction while reverse motion remains possible.
3. Confirm manual mode disables the driver in hardware.
4. Measure no-load, running, breakaway, stall, and clutch-slip current.
5. Install the real valve and repeat at minimum and maximum expected temperature, dry and wet.
6. Complete 500 bench cycles, then 5,000 endurance cycles before a sales pilot.
7. Perform water-ingress, condensation, UV, corrosion, brownout, blocked-valve, sensor-disconnect, and radio-loss tests.

## 9. SolidWorks Motion Study

Open `cad/native/AMR_50mm_Valve_Actuator.SLDASM`, select the `AMR_Valve_Open_Close` study, and calculate it before playback. It is a 6-second Basic Motion study with 10 rotary motor features: the 40T motor gear moves through 180 degrees while the 80T output group moves through 90 degrees in the opposite direction. The enclosure cover is visible in the saved assembly; suppress or hide it temporarily to inspect the drivetrain.

Run `tools/build_motion_study.ps1` after changing any native part, placement, or motor definition. Release only when `cad/motion/AMR_Valve_Open_Close_REPORT.txt` ends with `RESULT=PASS`, contains 35 resolved components and 10 features after calculation, and reports less than 0.01 mm gear-centre translation. The Motion Study is a kinematic design check and does not replace physical torque, clutch-slip, limit-switch, blocked-valve, or endurance testing.

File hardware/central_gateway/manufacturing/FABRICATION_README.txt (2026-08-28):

AMR CENTRAL GATEWAY v1.1-prototype
==================================

Board: 130 mm x 77 mm maximum outline, with ESP32 antenna notch
Material: FR-4
Finished thickness: 1.6 mm
Copper layers: 4
Suggested copper: 1 oz external and internal
Surface finish: ENIG preferred for prototype assembly; lead-free HASL acceptable

Layer order
-----------
L1  central_gateway-top_cu.gtl          Top copper
L2  central_gateway-gnd_plane.g1        Continuous GND plane
L3  central_gateway-signals.g2          Internal signals
L4  central_gateway-bottom_cu.gbl       Bottom copper with GND pour

Connector-specific notes
------------------------
J2 and J3 use the manufacturer footprint for Wuerth Elektronik 615006138421,
horizontal six-position RJ11-compatible modular jack, tab up. J10 is a two-pin JST XH header
for the enclosure-mounted normally-open setup/reset button; no PCB switch is
fitted. U2 is a soldered RFM95W-868S2 radio module and J9 is its SMA antenna port.

The archive includes front/back solder mask, front/back silkscreen, edge cuts,
a Gerber job file, separate plated and non-plated Excellon drill files, drill
maps/report, BOM, placement CSV, and the clean KiCad DRC report.

Important RF note
-----------------
The 0.45 mm antenna trace is a prototype starting value. It is NOT certified as
50 ohms for an arbitrary stack-up. Recalculate it from the fabricator's actual
L1-to-L2 dielectric thickness and dielectric constant, then validate the
assembled antenna path in its enclosure with a VNA.

Fabricator checks requested
---------------------------
1. Confirm all four copper layers and their order before manufacture.
2. Keep the ESP32 antenna notch exactly as defined by Edge.Cuts.
3. Keep NPTH mounting and connector locating holes non-plated.
4. Do not modify the RF trace or fill the antenna notch with copper.
5. Confirm the 0.90 mm contact drills and 2.36 mm locating holes for J2/J3.
6. Report annular-ring, solder-mask-web, or drill capability exceptions before production.

Release status
--------------
KiCad 10 DRC: 0 violations, 0 unconnected pads.
Firmware central_gateway build: successful after 16-direction vane calibration.
This package is for prototype/pilot fabrication and still requires engineering,
RF, EMC, surge, thermal, enclosure, and regulatory validation before sale.

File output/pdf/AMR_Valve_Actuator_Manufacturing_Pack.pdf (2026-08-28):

AMR Valve Actuator | Rev A-PROTOTYPE | NOT RELEASED FOR PRODUCTION | Sheet 1

# AMR 50 mm PVC VALVE ACTUATOR

# Manufacturing Drawing, BOM, Assembly, and Prototype Release Pack

# REVISION A-PROTOTYPE - NOT RELEASED FOR PRODUCTION OR SALE

## Motor: 5840-31ZY, 12 V, 40 rpm nominal, double shaft (real unit must be measured)

## Transmission: 40T/80T, module 1.5, PA20, 90.00 mm centre distance, 2:1 ratio

## Output: 20 mm shaft, dual 6204-2RS bearings, adjustable friction clutch, 30 mm manual hex

## Feedback: AS5600 on final shaft plus independent reeds and normally-closed hard limits

Structure: 6 mm 6061-T6 plates plus 16 mm bearing carriers and replaceable valve clamp/adapter

## Protection intent: IP65 minimum / IP67 preferred after production-intent ingress testing

## CRITICAL HOLD

Measure the actual motor, valve neck/stem, valve breakaway torque, and motor stall current before machining final interfaces.

The current repository TB6612 30 ms latching-valve firmware must not drive this continuous 12 V motor.


AMR Valve Actuator | Rev A-PROTOTYPE | NOT RELEASED FOR PRODUCTION | Sheet 2

# Resolved Assembly Envelope

Placed 50 mm configuration; purchased electronics are reference keep-out envelopes.

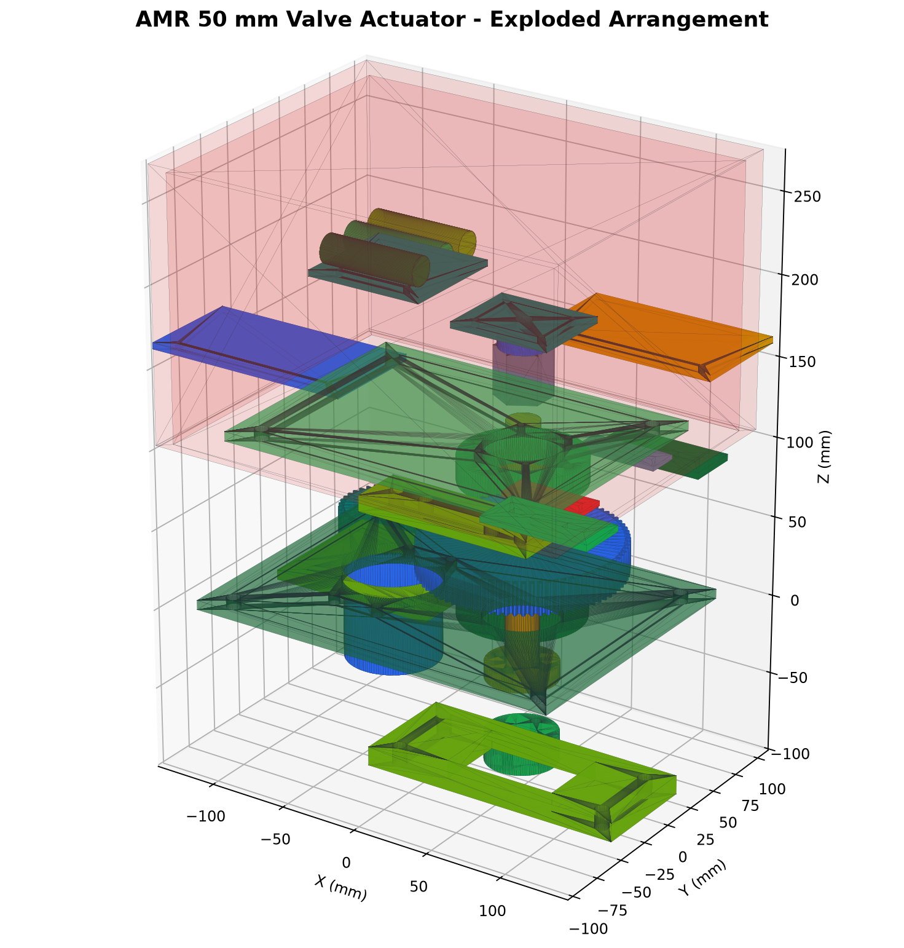
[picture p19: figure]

AMR Valve Actuator | Rev A-PROTOTYPE | NOT RELEASED FOR PRODUCTION | Sheet 3

# Exploded Assembly Arrangement

Exploded view is for component identification; use the written stack order for assembly.

AMR Valve Actuator | Rev A-PROTOTYPE | NOT RELEASED FOR PRODUCTION | Sheet 4

# Design Calculations and Protection Stack

Values are prototype sizing checks, not certification calculations.

Check | Equation / input | Result | Release interpretation
Gear ratio | 80 / 40 | 2.00:1 | Output speed 20 rpm nominal
Centre distance | m(z1+z2)/2 | 90.00 mm | Fixed datum; motor slots tune backlash
90 deg travel | 0.25 rev / 20 rpm | 0.75 s no-load | Use controlled PWM ramp; verify loaded time
Clutch preload | T/(2 mu r), T=8 Nm, mu=.30, r=25 mm | 533 N | Select/test Belleville stack; wet friction matters
Gear tangential load | T/r, T=8 Nm, r=60 mm | 133 N | 200 N at 12 Nm before impact factor
20 mm shaft torsion | 16T/(pi d^3), T=12 Nm | 7.6 MPa | Key, flange, pin, and fatigue govern
Stop reaction | T/L, T=12 Nm, L=45 mm | 267 N | Use >=4x impact factor for bracket check

# Protection sequence

AS5600 motion target | Reed confirmation | NC hard-limit interrupt | Steel M8 stop | Friction clutch slip

Final clutch torque is 1.5 times the highest measured valve breakaway torque only when that setting remains below the verified safe torque of the PVC stem, adapter bolts, printed gear teeth, motor gearbox, and stop structure. Measure dry/wet and hot/cold values; do not release using catalogue assumptions.

AMR Valve Actuator | Rev A-PROTOTYPE | NOT RELEASED FOR PRODUCTION | Sheet 5

# Mechanical BOM (1/2)

Item | Description | Qty | Material | Process | Critical note
P01 | Lower base plate | 1 | 6061-T6 | Laser/CNC + anodize | 240 x 180 x 6 mm
P02 | Upper support plate | 1 | 6061-T6 | Laser/CNC + anodize | 210 x 160 x 6 mm
P03 | Adjustable motor bracket | 1 | 6061-T6 | Laser/CNC + anodize | +/-5 mm mesh adjustment
P04 | 40T motor gear | 1 | PA12-CF | FDM + metal D insert | m1.5, PA20, 17 mm face
P05 | 80T clutch gear | 1 | PA12-CF | FDM + face finish | m1.5, PA20, 20 mm face
P06 | 20 mm output shaft/flange | 1 | 4140 or 316 SS | Turn/mill/grind | 20 h6 journals; 4 x M6 flange
P07 | Output gear clutch hub | 1 | C45 steel | Turn/keyway/zinc | OD50, bore20.1
P08 | Clutch pressure plate | 1 | C45 steel | Turn/grind/zinc | OD62, bore17.2, t5
P09 | Belleville stack | 1 | Spring steel | Purchased/calibrated | Initial preload about 530 N
P10 | Replaceable stem adapter | 1 | 17-4PH or PA12-CF | Machine/print | 44 x 18; stem HOLD
P11 | 50 mm valve bridge clamp | 1 | 6061-T6 | CNC + anodize | 72 mm HOLD opening
P12 | 63 mm alternative clamp | 1 | 6061-T6 | CNC + anodize | 88 mm HOLD opening; alternative
P13 | AS5600 bracket | 1 | 6061 or PA12-CF | Machine/print | Nonmagnetic, adjustable
P14 | Magnet carrier | 1 | PA12-CF | FDM | Final shaft mounting

AMR Valve Actuator | Rev A-PROTOTYPE | NOT RELEASED FOR PRODUCTION | Sheet 6

# Mechanical BOM (2/2)

Item | Description | Qty | Material | Process | Critical note
P15 | Reed cam ring | 1 | PA12-CF | FDM | Two adjustable magnets
P16 | OPEN reed bracket | 1 | 316 SS | Laser | Slotted
P17 | CLOSED reed bracket | 1 | 316 SS | Laser | Slotted
P18 | OPEN microswitch bracket | 1 | 316 SS | Laser | +/-5 deg adjustment
P19 | CLOSED microswitch bracket | 1 | 316 SS | Laser | +/-5 deg adjustment
P20 | Mechanical stop bracket | 1 | 6061 or steel | Machine | Two M8 stops
P21 | 3S1P battery tray | 1 | ASA/PA12-CF | FDM | 3 x protected 18650 envelope
P22 | TTGO tray | 1 | ASA/PA12-CF | FDM | USB service access
P23 | BTS7960 tray | 1 | ASA/PA12-CF | FDM | 25 mm heatsink clearance
P24 | Manual override hex | 1 | 316 SS | Turn/mill/passivate | 30 AF, bore20.2, cross-pin
P25 | Gasketed enclosure cover | 1 | UV PC/ASA | FDM/mould | IP65/IP67 design intent
P26 | Lower bearing carrier | 1 | 6061-T6 | Turn/mill/anodize | 47 H7 x 16; retainers
P27 | Upper bearing carrier | 1 | 6061-T6 | Turn/mill/anodize | 47 H7 x 16; retainers

AMR Valve Actuator | Rev A-PROTOTYPE | NOT RELEASED FOR PRODUCTION | Sheet 7

# Material and Electrical BOM

Item | Description | Qty | Specification | Release note
M01 | 5840-31ZY double-shaft gearmotor | 1 | 12 V, 40 rpm nominal | HOLD - measure supplier unit
M02 | 6204-2RS sealed bearing | 2 | 20 x 47 x 14 mm | Known standard
M03 | AS5600 angle module | 1 | 3.3 V I2C | Measure PCB and magnet gap
M04 | Diametric magnet | 1 | 6 x 2.5 mm target | Match AS5600 vendor guidance
M05 | Reed switch | 2 | Sealed dry contact | OPEN/CLOSED confirmation
M06 | Reed cam magnet | 2 | Small NdFeB, retained | Pot and mechanically capture
M07 | Long-lever microswitch | 2 | C/NO/NC, 250 VAC 5 A | Used at low-current control level
M08 | Manual interlock switch | 1 | Two-pole NC + auxiliary | Hardware driver disable
M09 | TTGO LoRa32 v2.1 | 1 | 868 MHz | Antenna separated from motor
M10 | BTS7960 / IBT-2 | 1 | High-current H bridge | Qualify against measured stall current
M11 | MCP23017 input expander | 1 | 3.3 V I2C | Reeds, limits, manual input
M12 | 3S BMS | 1 | Balancing + overcurrent | Rating from measured current
M13 | Protected 18650 cell | 3 | Matched cells, 3S1P | 12.6 V maximum
M14 | Fuse and holder | 1 | DC rated | Size after motor-current test
M15 | Logic DC/DC converter | 1 | 12.6 V input to stable logic rail | Automotive/transient capable
M16 | EPDM clamp liner | 1 | 3 mm sheet | Protect PVC body
M17 | EPDM enclosure gasket | 1 | Closed-cell | Compression verified by ingress test
M18 | Cable glands | 4 | IP68, sized to cables | Strain relief
M19 | Hydrophobic vent | 1 | IP67 pressure equalization | Above drainage plane
M20 | Friction washers | 2 | Oil/water-stable friction material | Torque test wet and dry
M21 | Bronze/steel gear sleeve | 1 | 30.0 mm nominal interface | Final tolerance after wear test

AMR Valve Actuator | Rev A-PROTOTYPE | NOT RELEASED FOR PRODUCTION | Sheet 8

# Fastener BOM

Item | Description | Qty | Use
F01 | M3 x 8 A4 socket screw | 12 | Electronics and sensor PCBs
F02 | M3 A4 Nyloc + washer | 12 | Electronics
F03 | M4 x 12 A4 socket screw | 8 | Sensor/reed brackets
F04 | M4 A4 Nyloc + washer | 8 | Sensor/reed brackets
F05 | M5 x 16 A4 socket screw | 8 | Microswitch and small structure
F06 | M5 A4 Nyloc + washer | 8 | Small structure
F07 | M6 x 20 A4 socket screw | 16 | Motor, carriers, shaft flange
F08 | M6 A4 Nyloc + washer | 16 | Motor, carriers, shaft flange
F09 | M8 x 70 A4 bolt | 4 | Valve bridge clamp; confirm length
F10 | M8 A4 Nyloc + large washer | 4 | Valve bridge clamp
F11 | M8 x 35 steel stop screw | 2 | Mechanical stops
F12 | M8 jam nut | 4 | Two per stop
F13 | M16 prevailing-torque nut | 1 | Clutch preload
F14 | M16 Belleville washers | 1 | Select stack for about 530 N initial preload
F15 | 6 x 6 mm parallel key | 1 | Output hub; length per hub
F16 | 5 mm stainless cross-pin | 1 | Manual override
F17 | 47 mm internal bearing retainer | 4 | Two per bearing carrier or drawing-equivalent plates
F18 | M4 A4 enclosure screw | 12 | Gasketed cover; captive preferred

# P01 Lower Base Plate

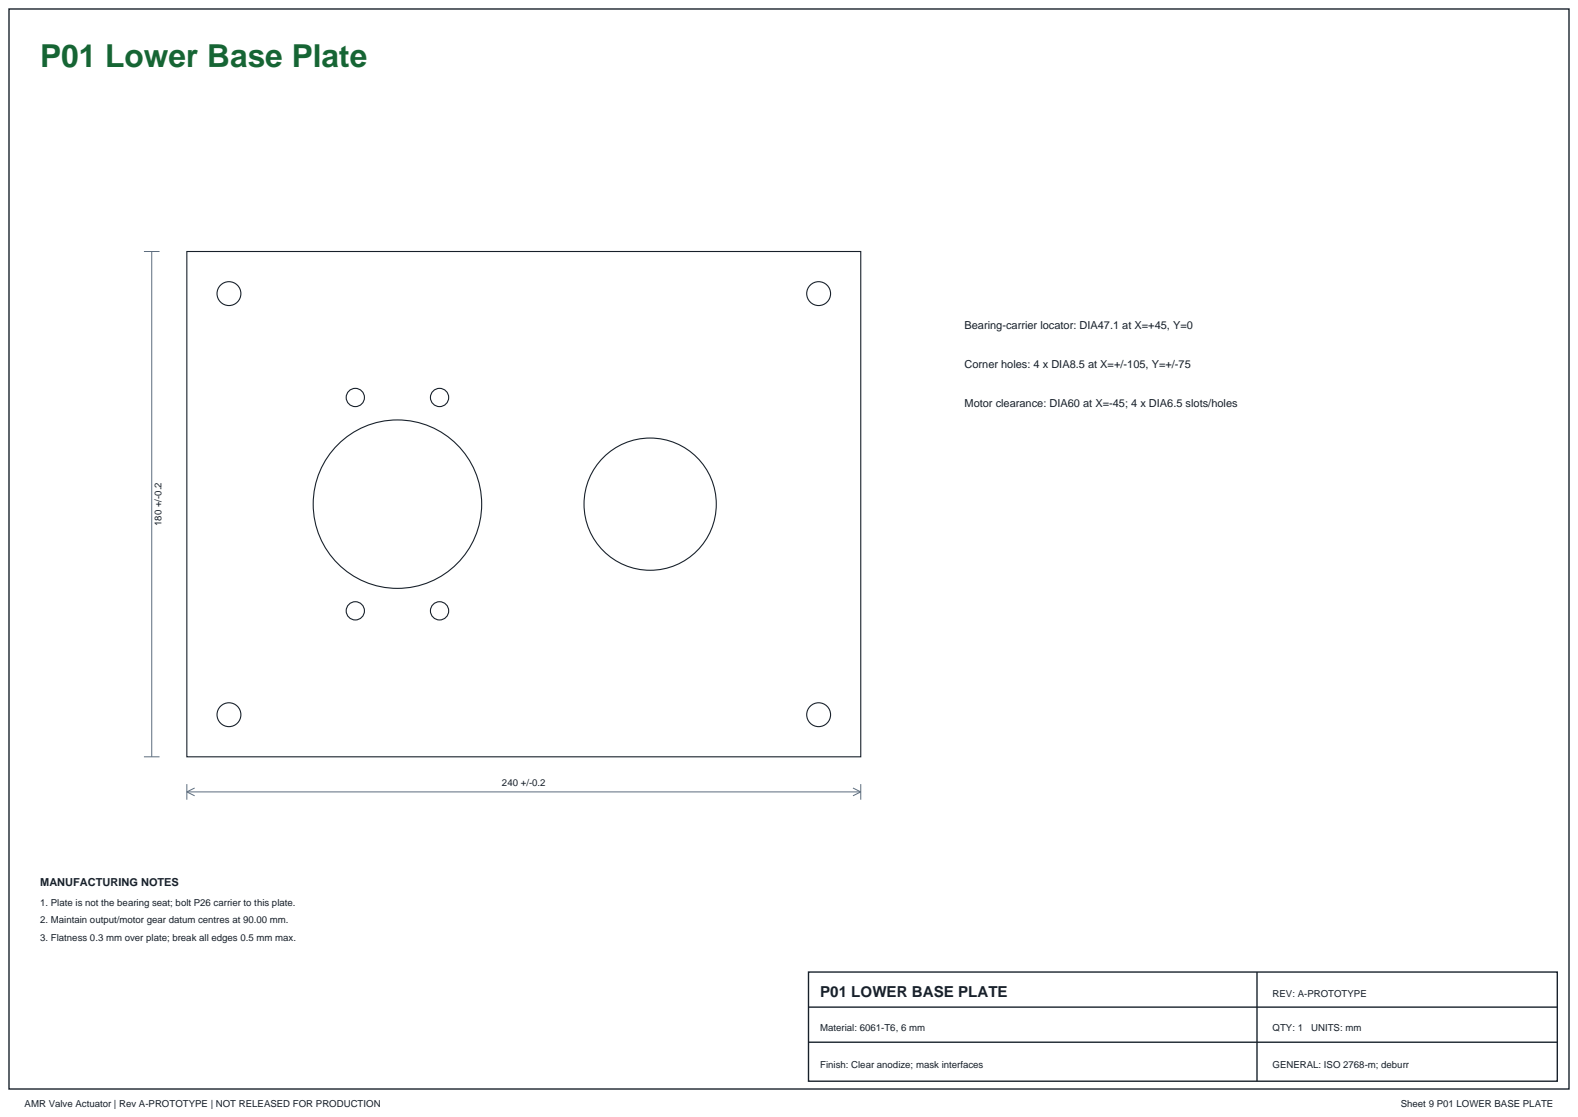
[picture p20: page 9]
AMR Valve Actuator | Rev A-PROTOTYPE | NOT RELEASED FOR PRODUCTION; Sheet 9 P01 LOWER BASE PLATE; MANUFACTURING NOTES

Bearing-carrier locator: DIA47.1 at X=+45, Y=0

Corner holes: 4 x DIA8.5 at X=+/-105, Y=+/-75

Motor clearance: DIA60 at X=-45; 4 x DIA6.5 slots/holes

1. Plate is not the bearing seat; bolt P26 carrier to this plate.
2. Maintain output/motor gear datum centres at 90.00 mm.
3. Flatness 0.3 mm over plate; break all edges 0.5 mm max.

P01 LOWER BASE PLATE | REV: A-PROTOTYPE

Material: 6061-T6, 6 mm | QTY: 1 UNITS: mm

Finish: Clear anodize; mask interfaces | GENERAL: ISO 2768-m; deburr

# P02 Upper Support Plate

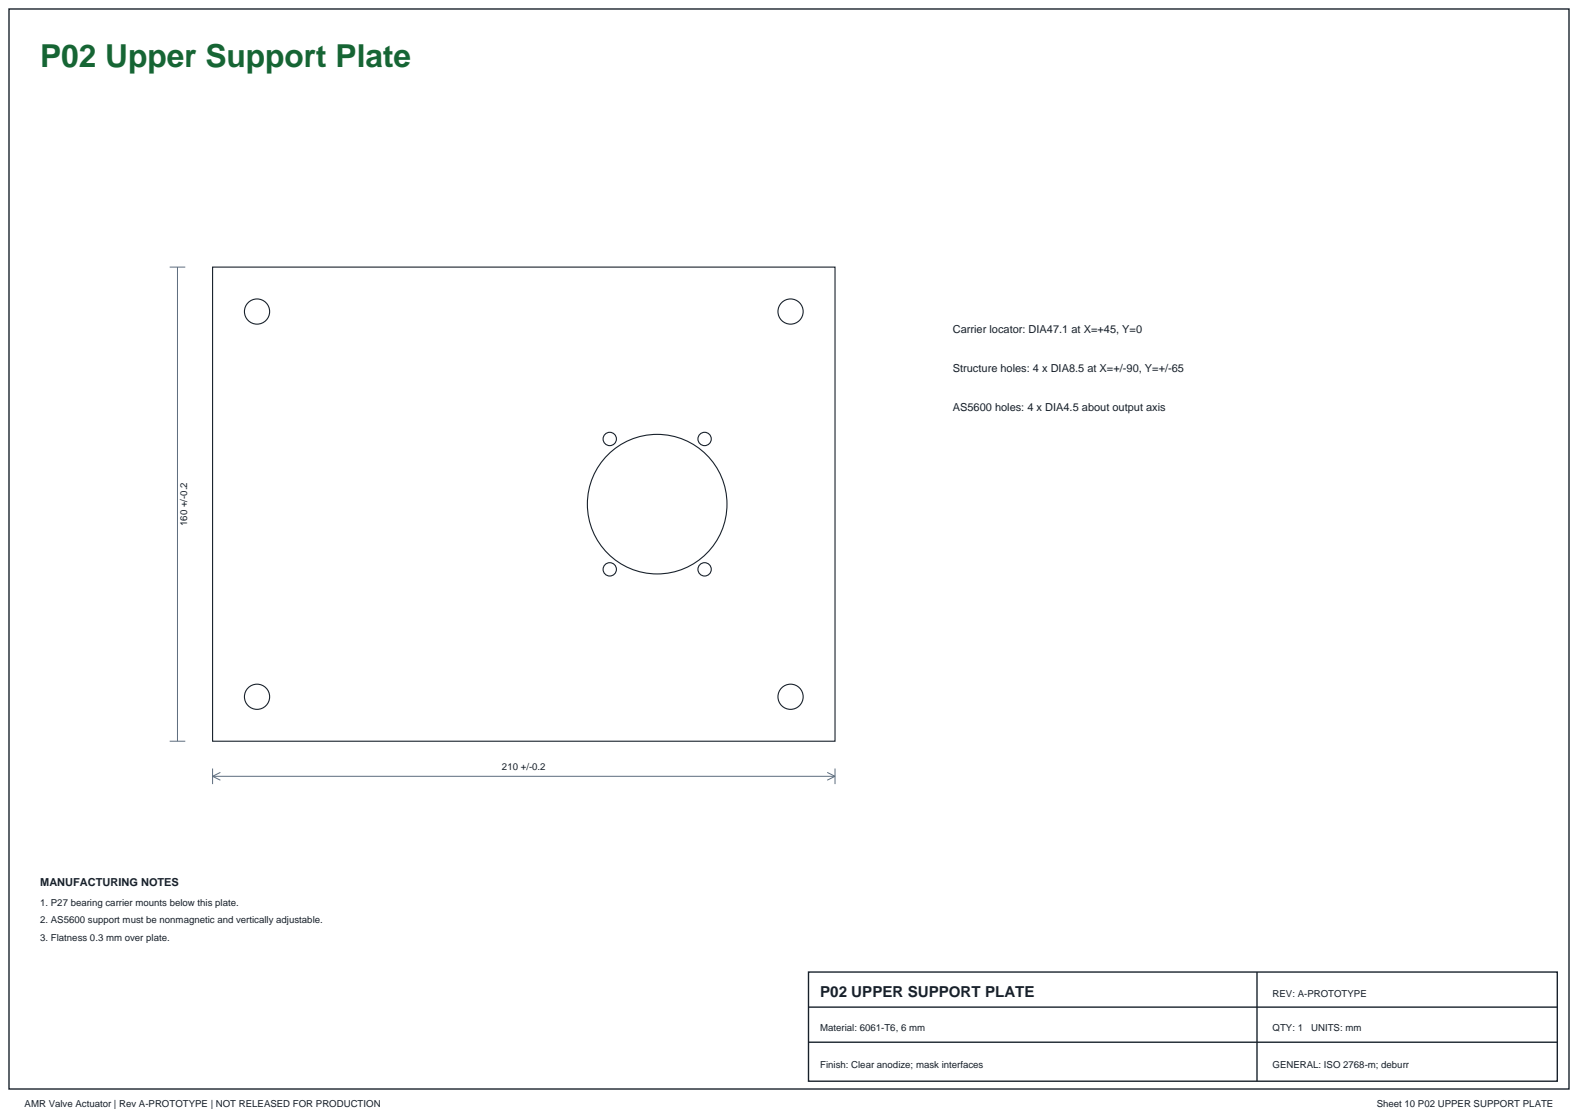
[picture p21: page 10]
AMR Valve Actuator | Rev A-PROTOTYPE | NOT RELEASED FOR PRODUCTION; Sheet 10 P02 UPPER SUPPORT PLATE; MANUFACTURING NOTES

Carrier locator: DIA47.1 at X=+45, Y=0

Structure holes: 4 x DIA8.5 at X=+/-90, Y=+/-65

AS5600 holes: 4 x DIA4.5 about output axis

1. P27 bearing carrier mounts below this plate.
2. AS5600 support must be nonmagnetic and vertically adjustable.
3. Flatness 0.3 mm over plate.

P02 UPPER SUPPORT PLATE | REV: A-PROTOTYPE

Material: 6061-T6, 6 mm | QTY: 1 UNITS: mm

Finish: Clear anodize; mask interfaces

# P03 Adjustable Motor Bracket

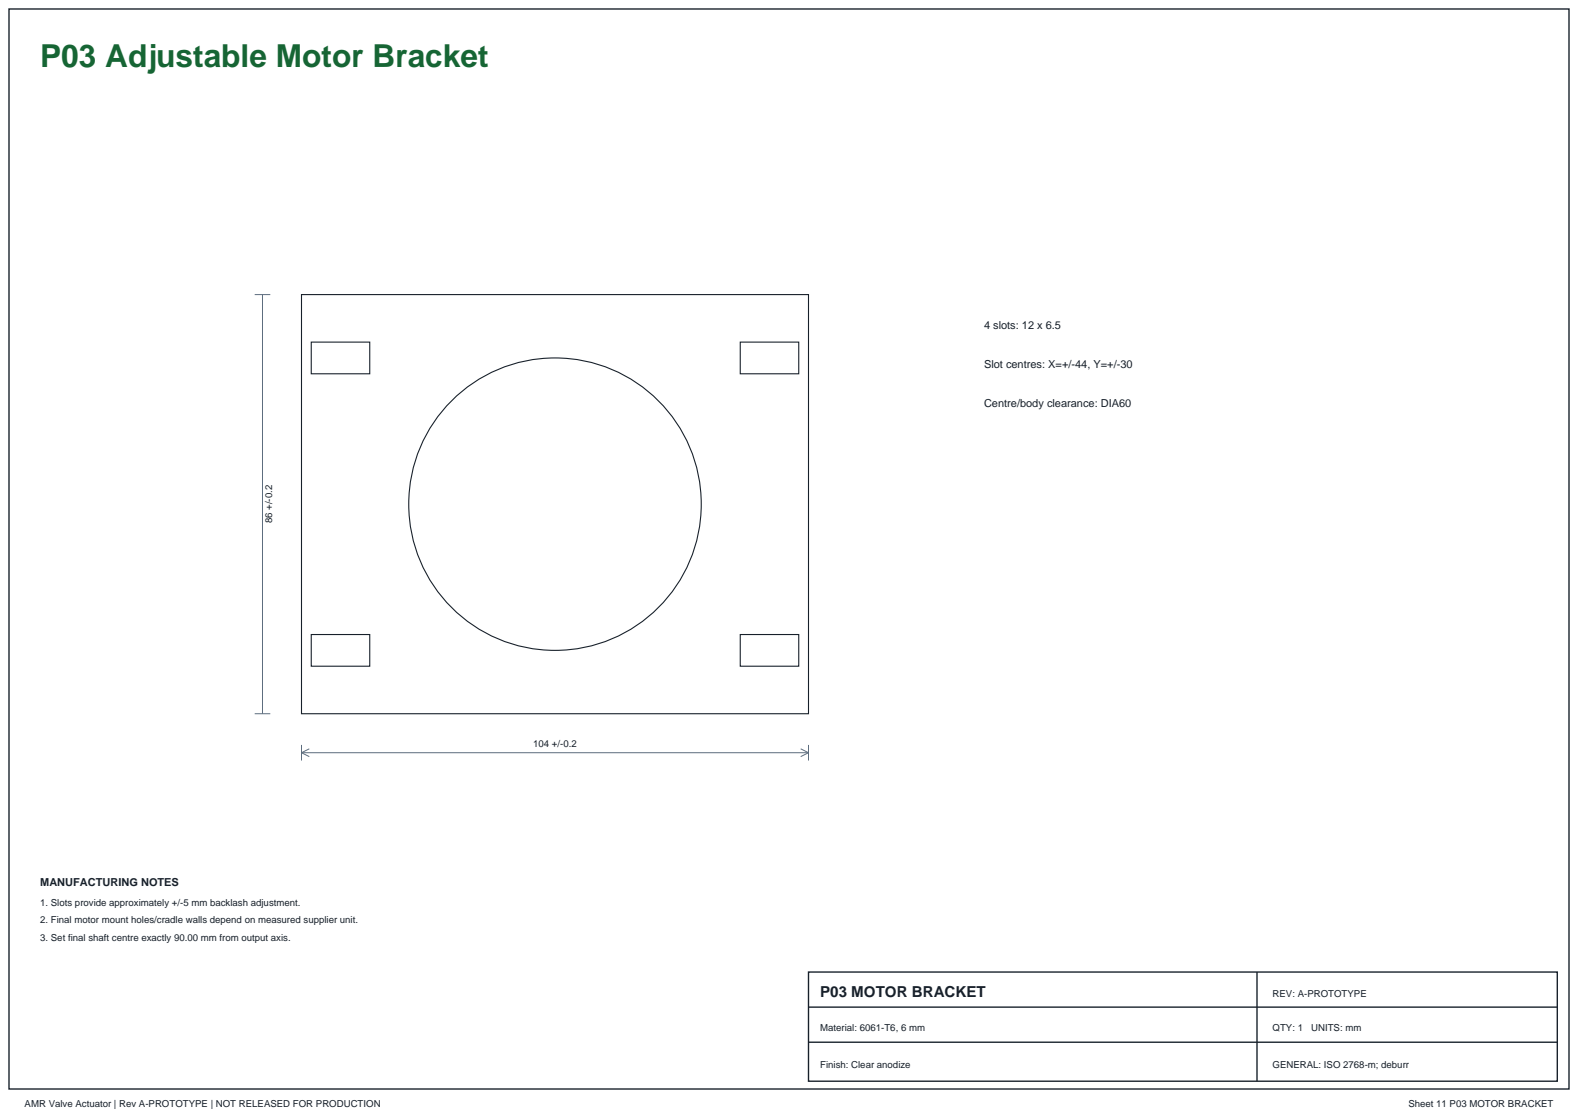
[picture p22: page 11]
AMR Valve Actuator | Rev A-PROTOTYPE | NOT RELEASED FOR PRODUCTION; Sheet 11 P03 MOTOR BRACKET; 4 slots: 12 x 6.5; Slot centres: X=+/-44, Y=+/-30; MANUFACTURING NOTES

Centre/body clearance: DIA60

1. Slots provide approximately +/-5 mm backlash adjustment.
2. Final motor mount holes/cradle walls depend on measured supplier unit.
3. Set final shaft centre exactly 90.00 mm from output axis.

P03 MOTOR BRACKET | REV: A-PROTOTYPE

Material: 6061-T6, 6 mm | QTY: 1 UNITS: mm

Finish: Clear anodize

# P06 Output Shaft and Adapter Flange 161 +/-0.1

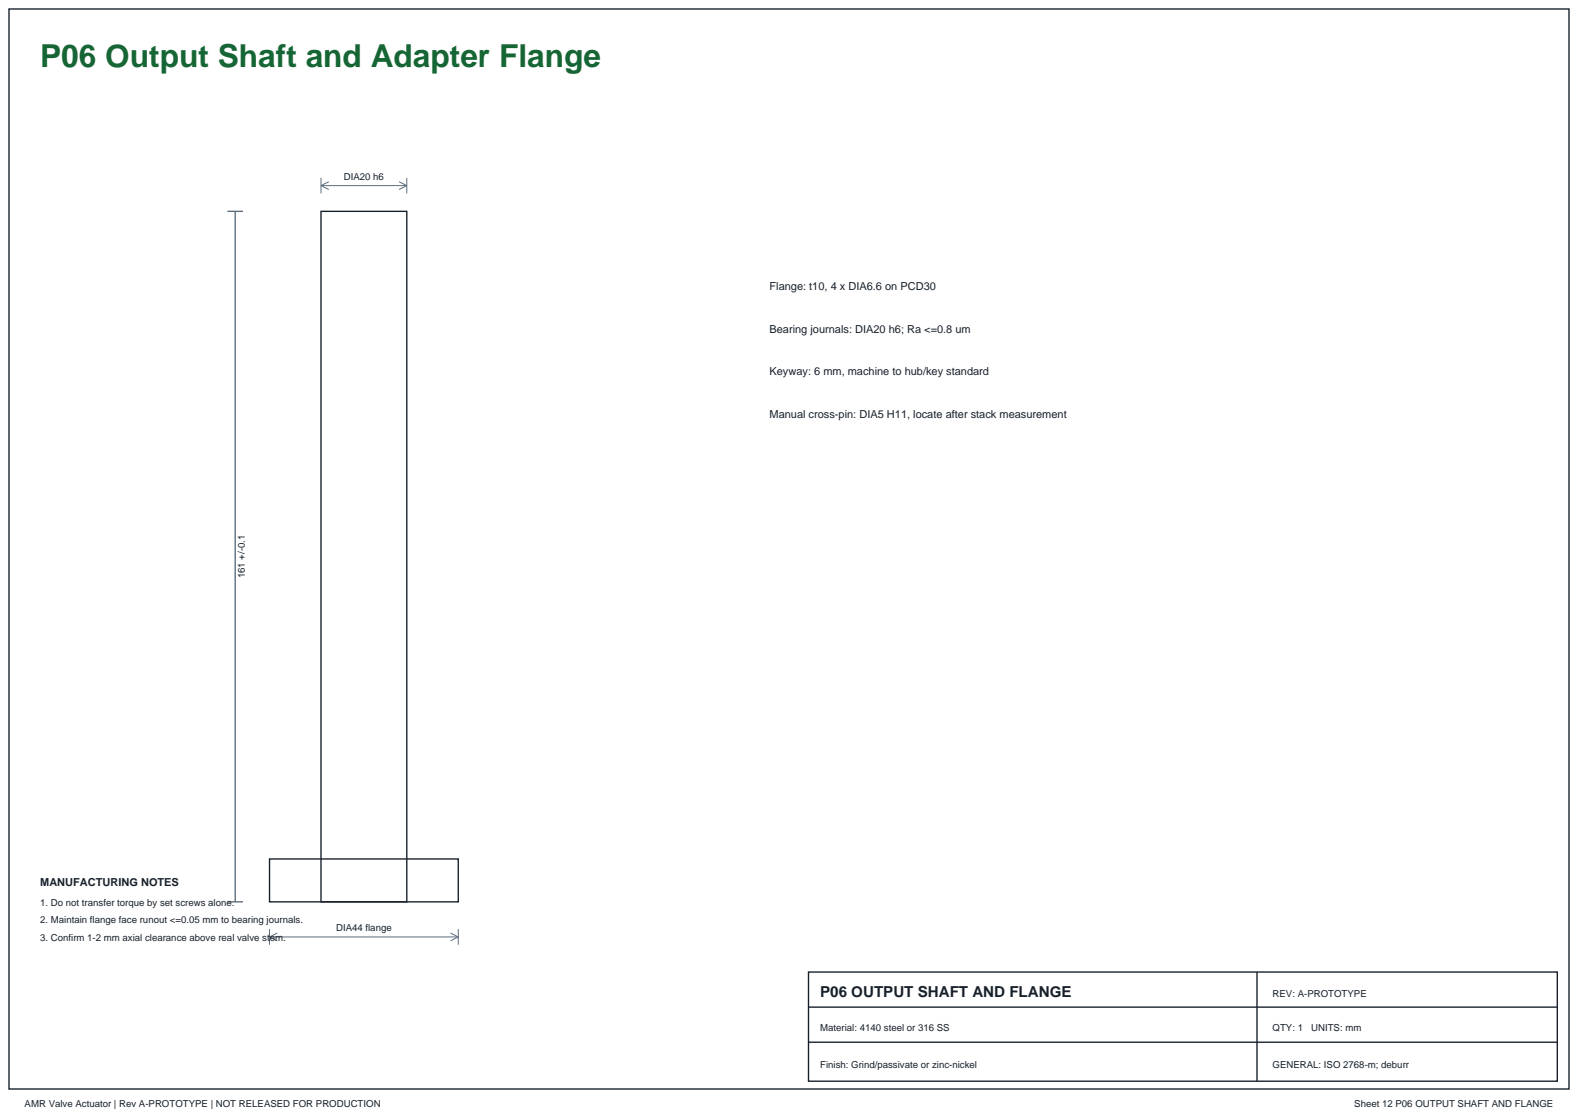
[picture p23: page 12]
AMR Valve Actuator | Rev A-PROTOTYPE | NOT RELEASED FOR PRODUCTION; Sheet 12 P06 OUTPUT SHAFT AND FLANGE; REV: A-PROTOTYPE; DIA20 h6; DIA44 flange; Flange: t10, 4 x DIA6.6 on PCD30; MANUFACTURING NOTES

Bearing journals: DIA20 h6; Ra <=0.8 um

Keyway: 6 mm, machine to hub/key standard

Manual cross-pin: DIA5 H11, locate after stack measurement

1. Do not transfer torque by set screws alone.
2. Maintain flange face runout <=0.05 mm to bearing journals.
3. Confirm 1-2 mm axial clearance above real valve stem.

P06 OUTPUT SHAFT AND FLANGE

Material: 4140 steel or 316 SS

QTY: 1 UNITS: mm

Finish: Grind/passivate or zinc-nickel

# P10 Replaceable Valve Stem Adapter

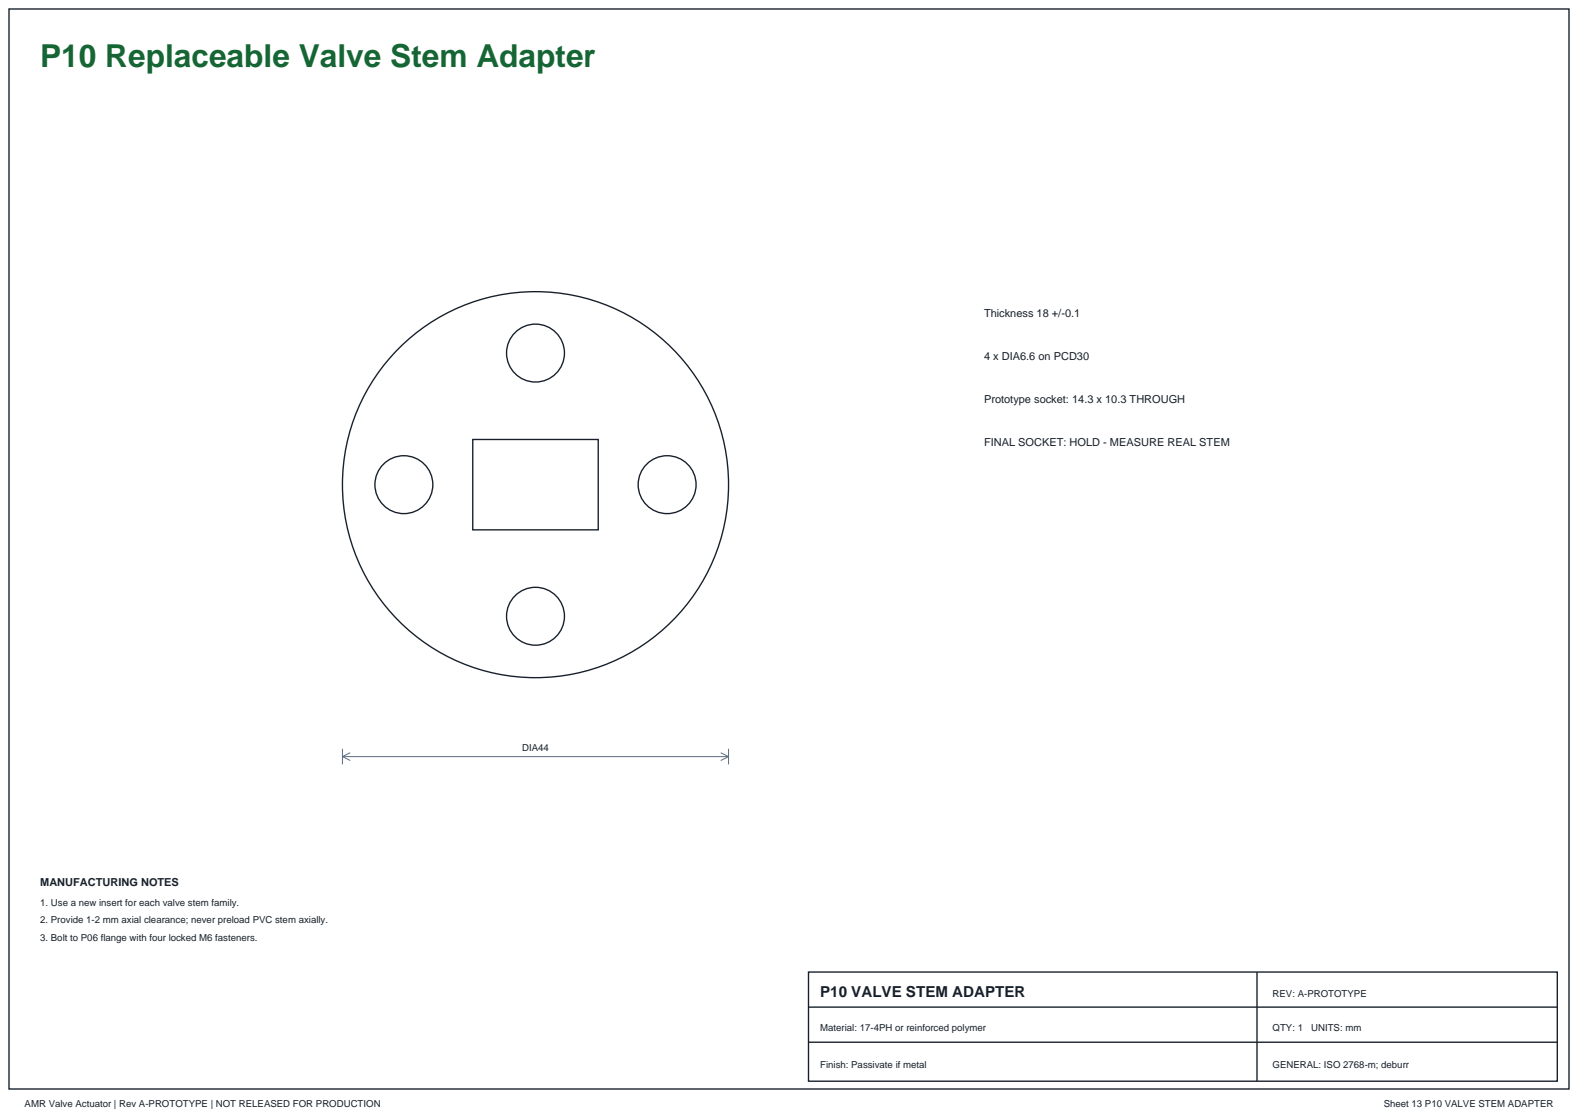
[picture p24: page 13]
AMR Valve Actuator | Rev A-PROTOTYPE | NOT RELEASED FOR PRODUCTION; Sheet 13 P10 VALVE STEM ADAPTER; DIA44; Thickness 18 +/-0.1; 4 x DIA6.6 on PCD30; MANUFACTURING NOTES

Prototype socket: 14.3 x 10.3 THROUGH

FINAL SOCKET: HOLD - MEASURE REAL STEM

1. Use a new insert for each valve stem family.
2. Provide 1-2 mm axial clearance; never preload PVC stem axially.
3. Bolt to P06 flange with four locked M6 fasteners.

P10 VALVE STEM ADAPTER | REV: A-PROTOTYPE

Material: 17-4PH or reinforced polymer | QTY: 1 UNITS: mm

Finish: Passivate if metal

# P07 Clutch Output Hub

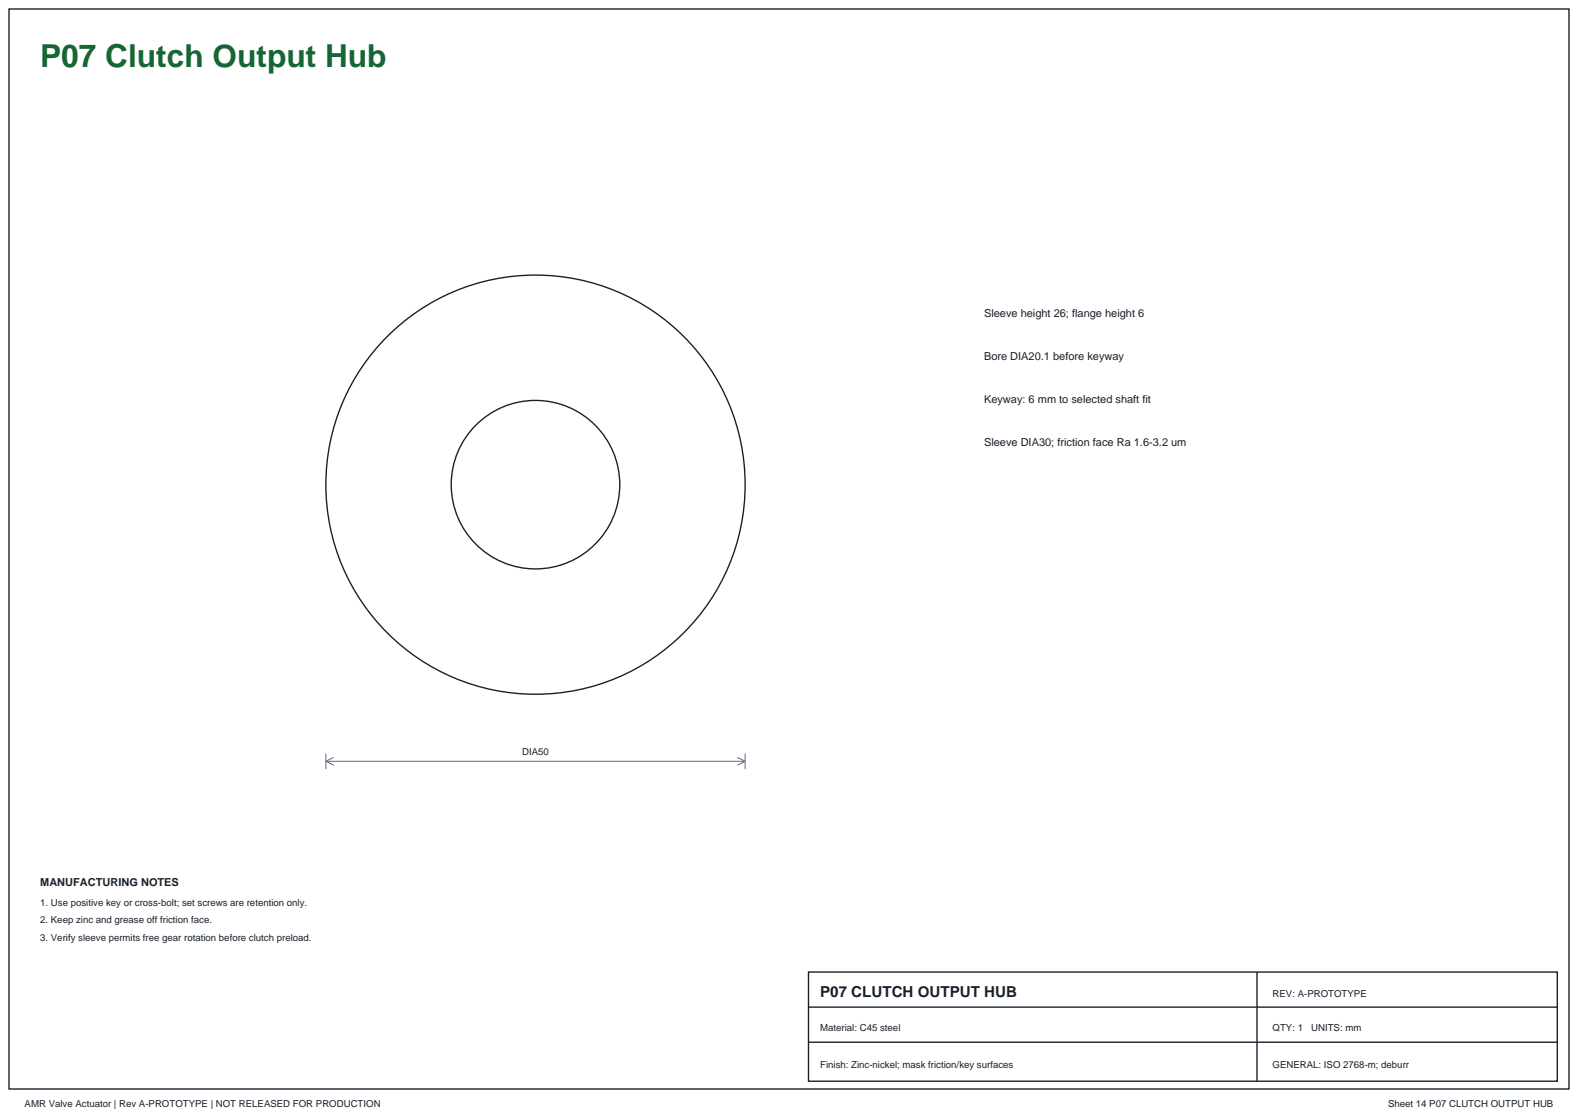
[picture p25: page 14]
AMR Valve Actuator | Rev A-PROTOTYPE | NOT RELEASED FOR PRODUCTION; Sheet 14 P07 CLUTCH OUTPUT HUB; DIA50; MANUFACTURING NOTES

Sleeve height 26; flange height 6

Bore DIA20.1 before keyway

Keyway: 6 mm to selected shaft fit

Sleeve DIA30; friction face Ra 1.6-3.2 um

1. Use positive key or cross-bolt; set screws are retention only.
2. Keep zinc and grease off friction face.
3. Verify sleeve permits free gear rotation before clutch preload.

P07 CLUTCH OUTPUT HUB | REV: A-PROTOTYPE

Material: C45 steel | QTY: 1 UNITS: mm

Finish: Zinc-nickel; mask friction/key surfaces

# P18/P19 OPEN and CLOSED Microswitch Brackets

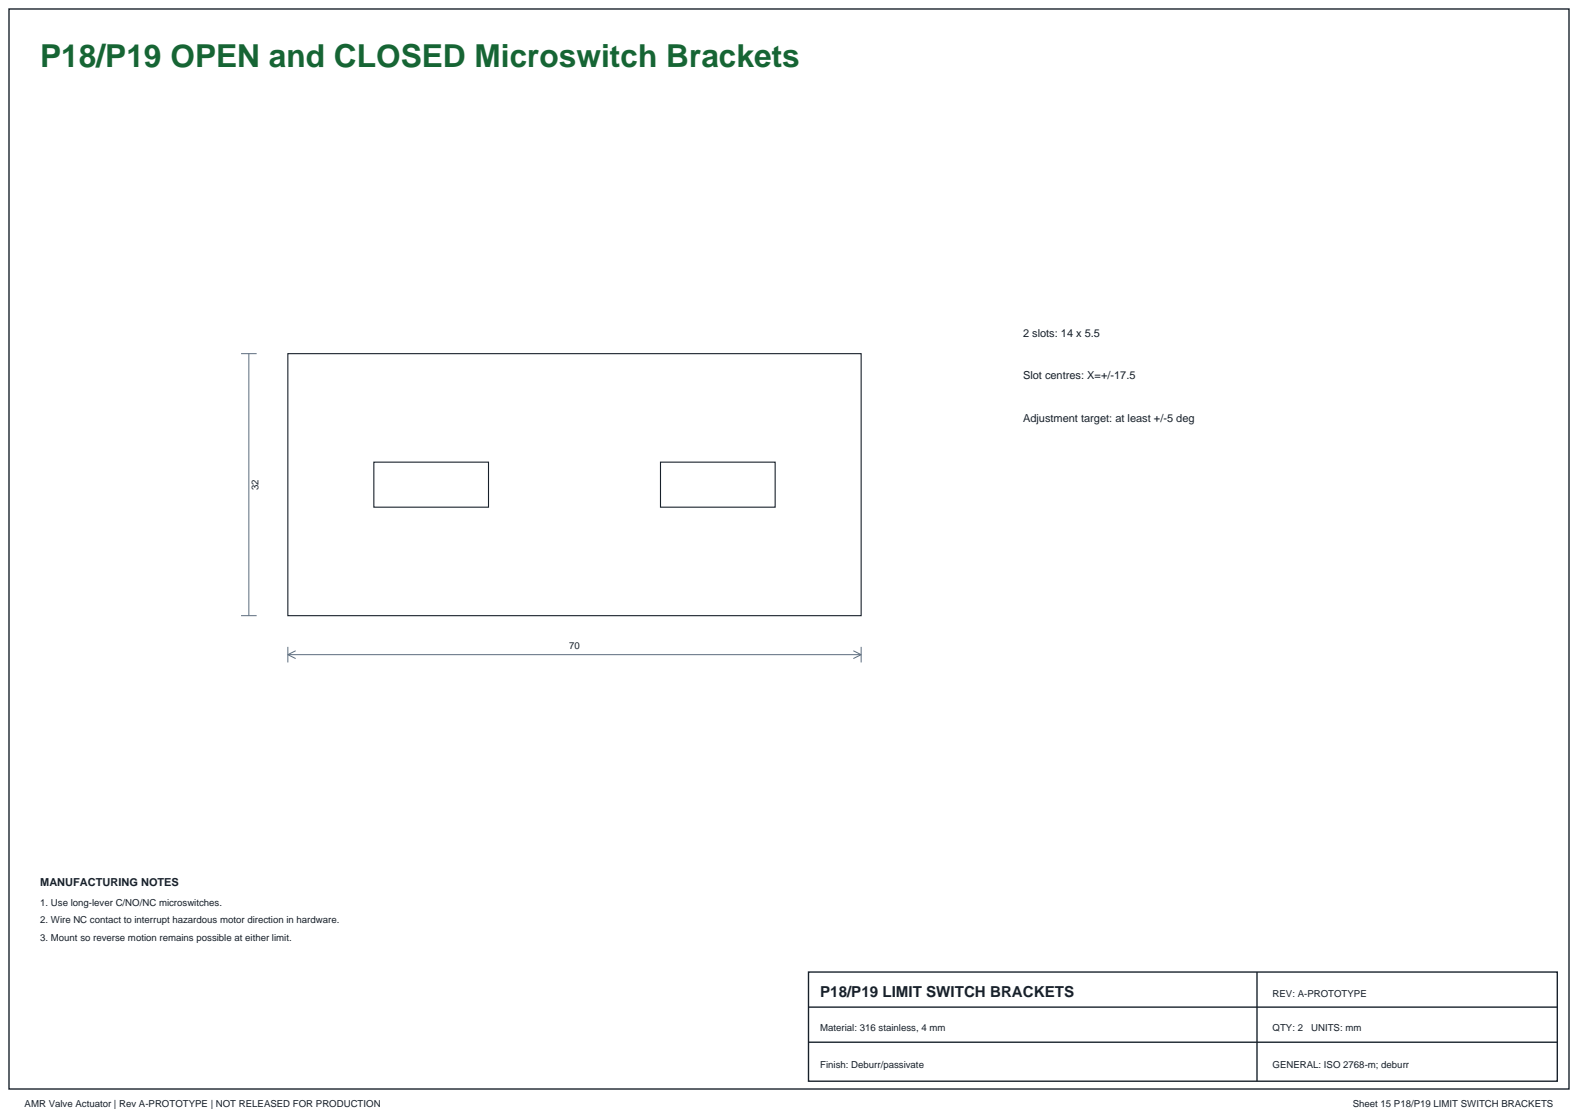
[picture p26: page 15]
AMR Valve Actuator | Rev A-PROTOTYPE | NOT RELEASED FOR PRODUCTION; Sheet 15 P18/P19 LIMIT SWITCH BRACKETS; 2 slots: 14 x 5.5; Slot centres: X=+/-17.5; MANUFACTURING NOTES

Adjustment target: at least +/-5 deg

1. Use long-lever C/NO/NC microswitches.
2. Wire NC contact to interrupt hazardous motor direction in hardware.
3. Mount so reverse motion remains possible at either limit.

P18/P19 LIMIT SWITCH BRACKETS | REV: A-PROTOTYPE

Material: 316 stainless, 4 mm | QTY: 2 UNITS: mm

Finish: Deburr/passivate

# P13 AS5600 Adjustable Bracket

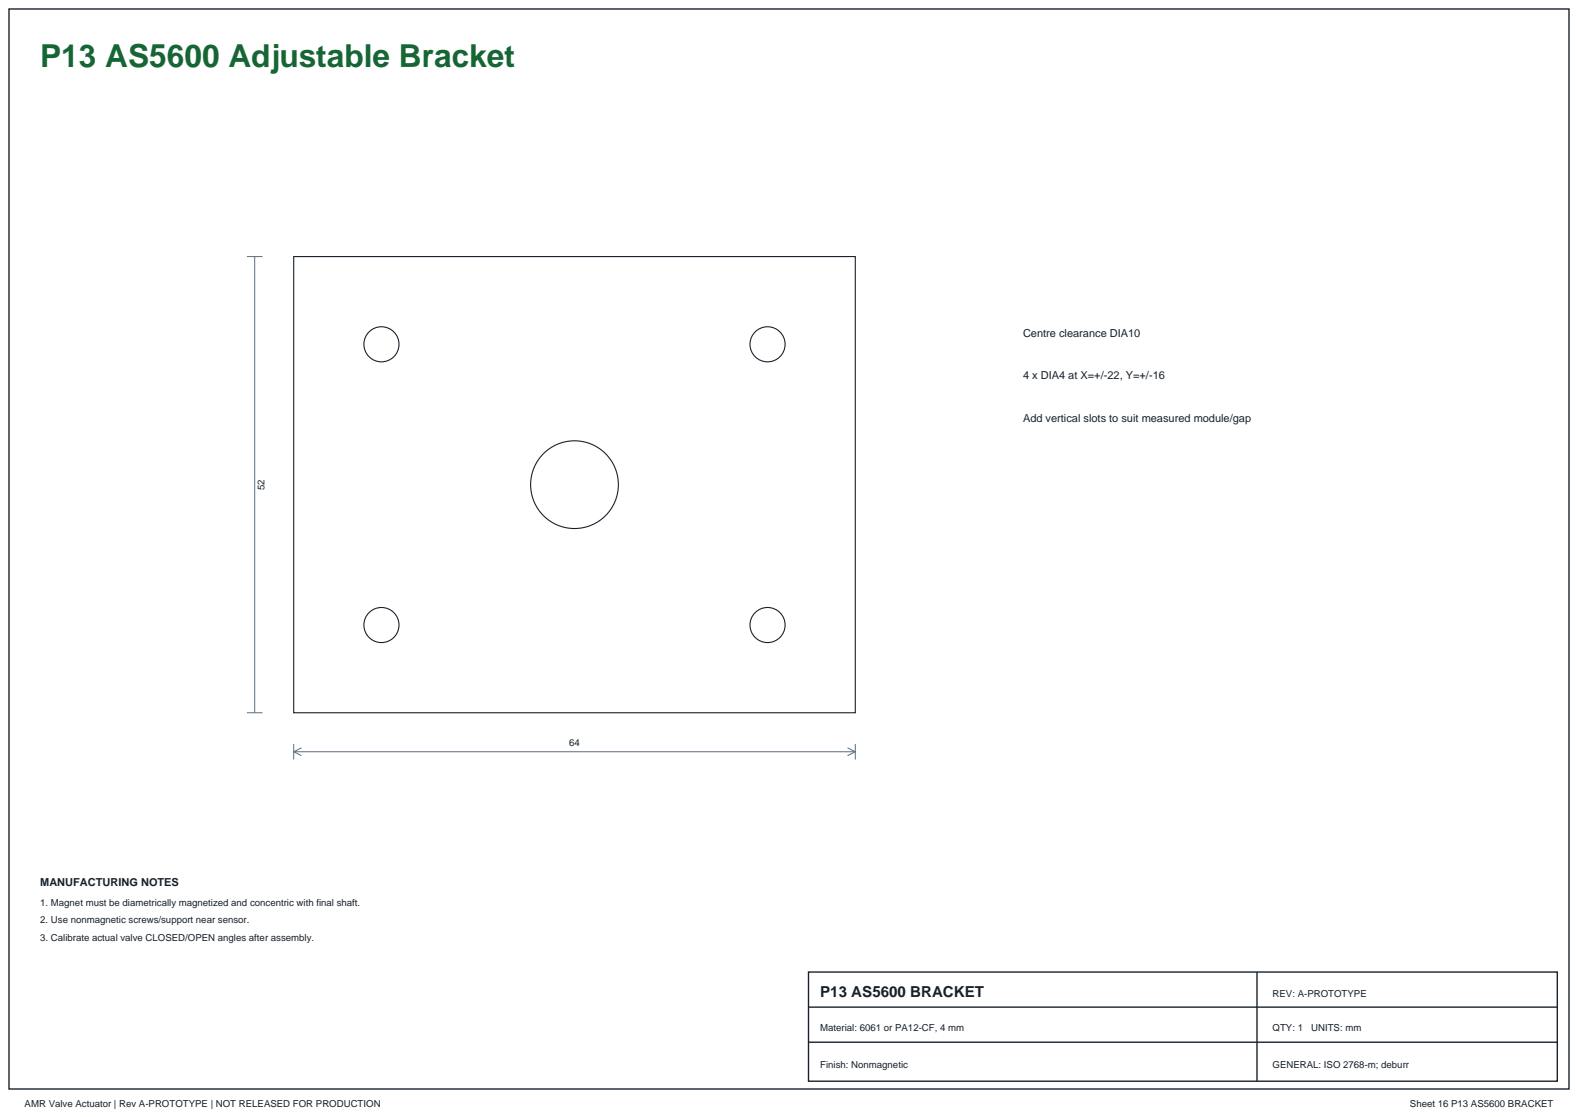
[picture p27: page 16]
AMR Valve Actuator | Rev A-PROTOTYPE | NOT RELEASED FOR PRODUCTION; Sheet 16 P13 AS5600 BRACKET; Centre clearance DIA10; 4 x DIA4 at X=+/-22, Y=+/-16; MANUFACTURING NOTES

Add vertical slots to suit measured module/gap

1. Magnet must be diametrically magnetized and concentric with final shaft.
2. Use nonmagnetic screws/support near sensor.
3. Calibrate actual valve CLOSED/OPEN angles after assembly.

P13 AS5600 BRACKET | REV: A-PROTOTYPE

Material: 6061 or PA12-CF, 4 mm | QTY: 1 UNITS: mm

Finish: Nonmagnetic

# P11 50 mm Valve Bridge Clamp

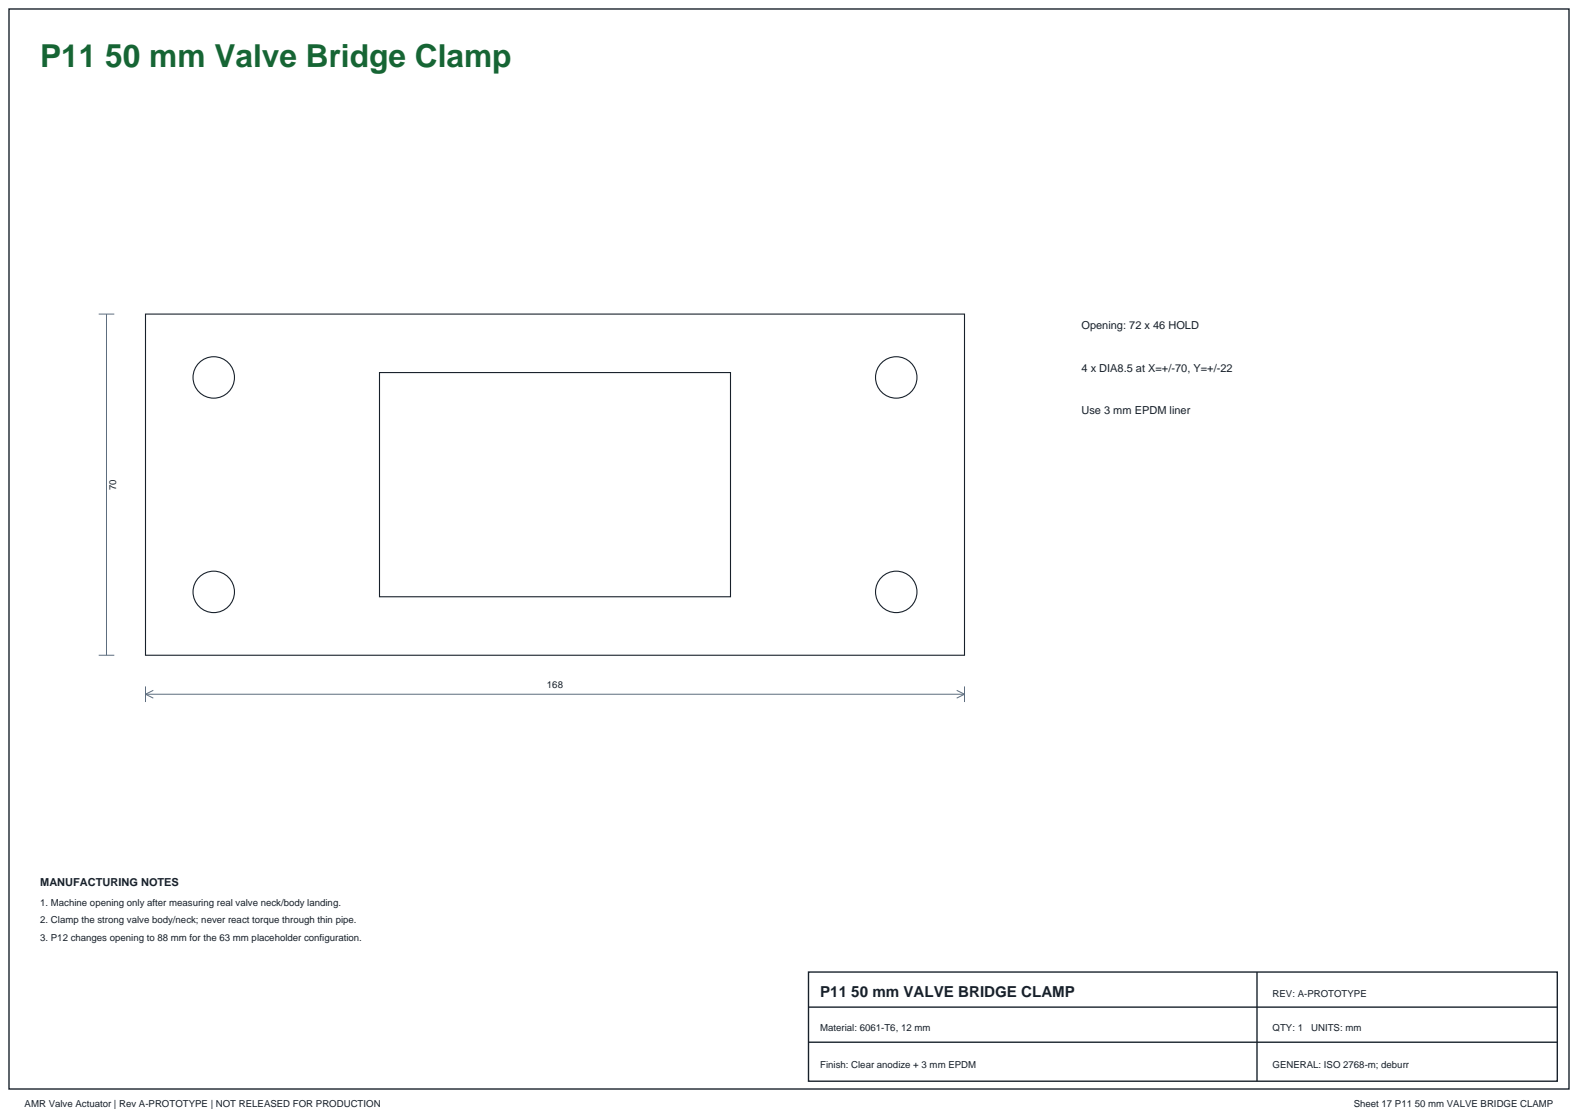
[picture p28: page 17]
AMR Valve Actuator | Rev A-PROTOTYPE | NOT RELEASED FOR PRODUCTION; Sheet 17 P11 50 mm VALVE BRIDGE CLAMP; Opening: 72 x 46 HOLD; 4 x DIA8.5 at X=+/-70, Y=+/-22; MANUFACTURING NOTES

Use 3 mm EPDM liner

1. Machine opening only after measuring real valve neck/body landing.
2. Clamp the strong valve body/neck; never react torque through thin pipe.
3. P12 changes opening to 88 mm for the 63 mm placeholder configuration.

P11 50 mm VALVE BRIDGE CLAMP | REV: A-PROTOTYPE

Material: 6061-T6, 12 mm | QTY: 1 UNITS: mm

Finish: Clear anodize + 3 mm EPDM

# P26/P27 6204 Bearing Carriers

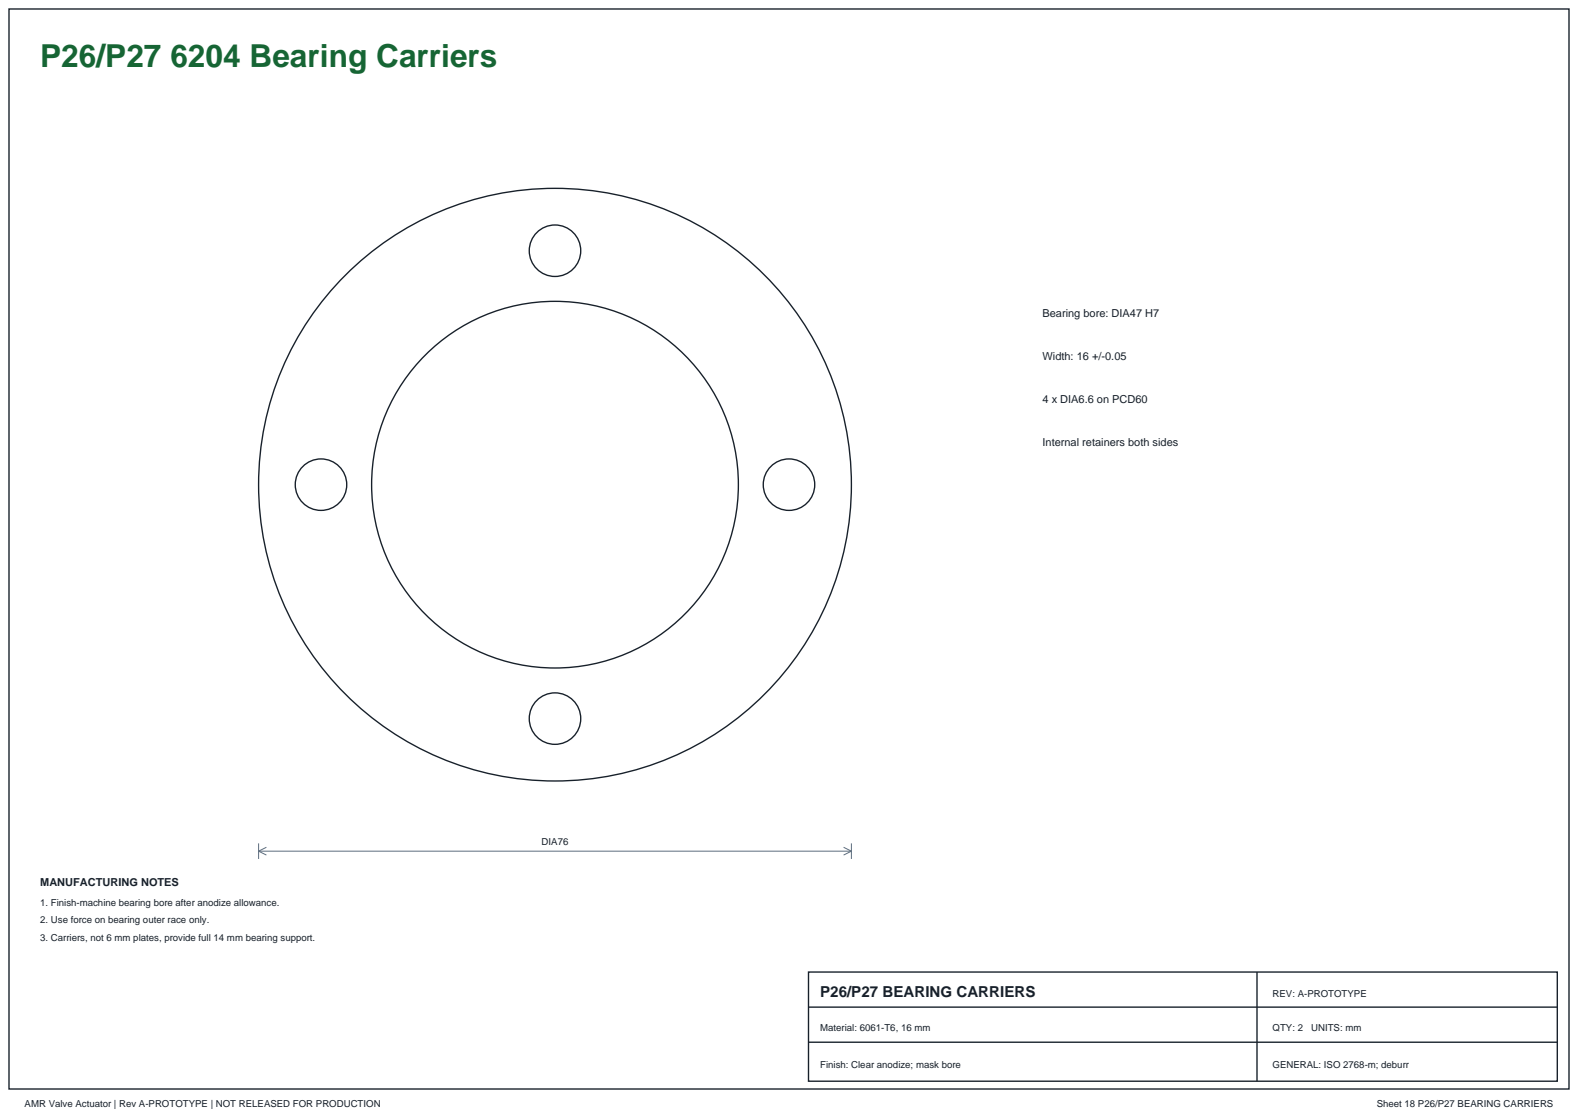
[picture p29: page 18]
AMR Valve Actuator | Rev A-PROTOTYPE | NOT RELEASED FOR PRODUCTION; Sheet 18 P26/P27 BEARING CARRIERS; DIA76; Bearing bore: DIA47 H7; Width: 16 +/-0.05; 4 x DIA6.6 on PCD60; MANUFACTURING NOTES

Internal retainers both sides

1. Finish-machine bearing bore after anodize allowance.
2. Use force on bearing outer race only.
3. Carriers, not 6 mm plates, provide full 14 mm bearing support.

P26/P27 BEARING CARRIERS | REV: A-PROTOTYPE

Material: 6061-T6, 16 mm | QTY: 2 UNITS: mm

Finish: Clear anodize; mask bore

AMR Valve Actuator | Rev A-PROTOTYPE | NOT RELEASED FOR PRODUCTION | Sheet 19

# Assembly and Calibration Sequence

1 Measure motor and valve; machine HOLD interfaces only after inspection approval.

2

Install 6204 bearings in P26/P27 carriers and bolt carriers to P01/P02.

3

Install P06 shaft, P10 measured adapter, valve clamp, and verify 1-2 mm axial clearance.

4

Install motor and 40T/80T gears at 90.00 mm centres; tune 0.25-0.35 mm backlash.

5 Assemble clutch: hub, friction washer, gear, friction washer, pressure plate, Belleville stack, M16 locknut.

6

Install AS5600, reed cams, hard limits, steel stops, and manual hardware interlock.

7 Calibrate clutch from 8 N m and set final torque from measured valve data.

8 Bench test current-limited, then complete ingress, fault, temperature, radio, and endurance tests.

## DO NOT CONNECT TO CURRENT TB6612 PULSE FIRMWARE

This actuator requires continuous bidirectional PWM, AS5600 feedback, independent reeds/limits, manual inhibit, movement timeout, and current/stall protection.

Both hard limits and manual mode must remove hazardous motor drive through hardware, even if the MCU or software fails.

AMR Valve Actuator | Rev A-PROTOTYPE | NOT RELEASED FOR PRODUCTION | Sheet 20

# Prototype Release Hold Points

Status | Hold point | Evidence required
OPEN | Motor interface | Body, mount, shaft, D-flat, projection, stall current at 9.0/11.1/12.6 V
OPEN | Valve interface | Neck/body, stem profile/height, axial float, breakaway and running torque wet/dry/hot/cold
OPEN | Power train | Gear contact, backlash, key/pin/flange, clutch wet/dry torque, stop impact load
OPEN | Electronics | Driver/BMS/fuse/wire ratings, surge/ESD/reverse polarity, brownout and thermal behavior
OPEN | Functional safety | Two hard limits, manual inhibit, AS5600 faults, no motion, reversed motion, timeout, radio loss
OPEN | Environment | IP65/IP67, condensation, UV, corrosion, vibration, temperature, EMC and LoRa coexistence
OPEN | Durability | 500 engineering cycles and 5,000 production-intent pilot cycles
OPEN | Commercial | Risk assessment, labels, traceability, instructions, maintenance, warranty, Tunisian compliance review

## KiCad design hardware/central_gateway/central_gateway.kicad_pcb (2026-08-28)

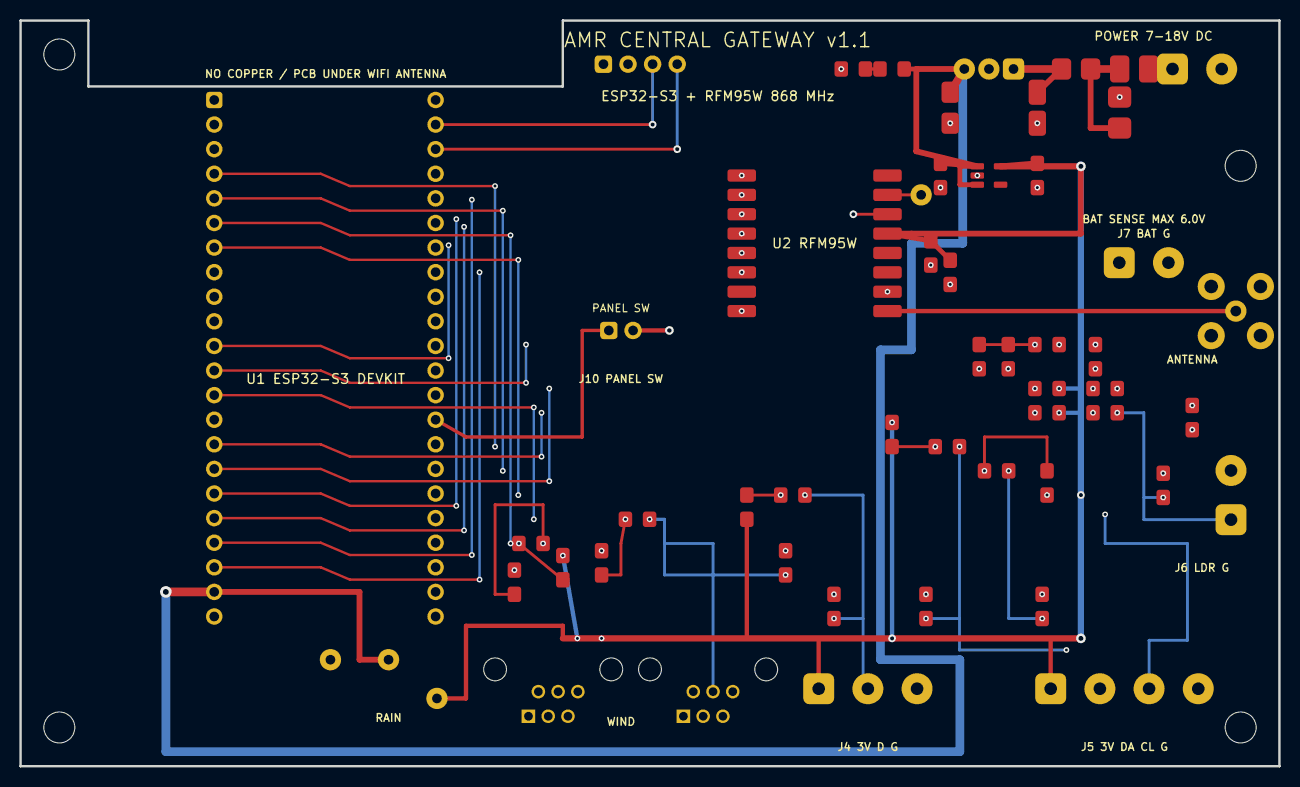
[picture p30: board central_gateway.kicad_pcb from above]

Board: 4 copper layers, 130.0 x 77.0 mm, 58 parts (0 on the bottom side), 34 nets.

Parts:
C1: 10uF 35V; AMR_Central_C_1210
C2: 22uF 10V; AMR_Central_C_1206
C3, C4: 1uF; AMR_Central_C_0805
C5: 10uF; AMR_Central_C_0805
C6, C11: 100nF; AMR_Central_C_0805
D1: SMBJ18A; AMR_Central_D_SMB
D2: SS34; AMR_Central_D_SMA
D3, D4, D5, D6, D7, D8, D9: PESD3V3; AMR_Central_D_SOD323
D10: BZT52C6V2; AMR_Central_D_SOD323
F1: PTC 0.75A; AMR_Central_Fuse_1812
H1, H2, H3, H4: M3; AMR_Central_MountingHole_3.2mm
J1: POWER 7-18V DC; AMR_Central_TerminalBlock_2
J2: RAIN RJ11; AMR_Central_WR-MJ_615006138421
J3: WIND+VANE RJ11; AMR_Central_WR-MJ_615006138421
J4: DHT11; AMR_Central_TerminalBlock_3
J5: BMP280 I2C; AMR_Central_TerminalBlock_4
J6: PASSIVE LDR; AMR_Central_TerminalBlock_2
J7: BAT SENSE 0-6V; AMR_Central_TerminalBlock_2
J8: SERVICE UART; AMR_Central_Header_1x4
J9: SMA_868MHz; AMR_Central_SMA_Vertical_THT
J10: PANEL SETUP BUTTON; AMR_Central_JST_XH_B2B-XH-A_1x02_P2.50mm
LED1: GREEN; AMR_Central_LED_0805
R1, R2, R4, R12, R14: 1k; AMR_Central_R_0805
R3, R5, R13, R15: 10k; AMR_Central_R_0805
R6: 220R; AMR_Central_R_0805
R7, R10, R11: 4.7k; AMR_Central_R_0805
R8, R9: 100R; AMR_Central_R_0805
R16, R17: 100k 1%; AMR_Central_R_0805
TP1: +5V; AMR_Central_TestPoint_THT
TP2: +3V3; AMR_Central_TestPoint_THT
TP3: GND; AMR_Central_TestPoint_THT
TP4: LORA_DIO1; AMR_Central_TestPoint_THT
U1: ESP32-S3-DevKitC-1-N8R8; AMR_Central_ESP32-S3-DevKitC-1_Carrier
U2: RFM95W-868S2; AMR_Central_HOPERF_RFM95W_SMD
U3: R-78E5.0-1.0; AMR_Central_RECOM_R-78E5.0-1.0_SIP3
U4: AP2112K-3.3; AMR_Central_SOT-23-5

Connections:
+3V3_PERIPH: C4.2, C5.2, C6.2, J4.1, J5.1, J8.1, R3.2, R5.2, R7.1, R10.2, R11.1, R13.2, R15.2, TP2.1, U2.13 (3V3), U4.5 (VOUT)
+5V: C2.2, C3.2, R1.2, TP1.1, U1.21 (5V), U3.3 (VOUT), U4.1 (VIN), U4.3 (EN)
BATT_ADC: C11.2, R16.1, R17.2, U1.12 (GPIO8)
BATT_SENSE_RAW: D10.1, J7.1, R16.2
DHT_GPIO: R6.1, R7.2, U1.7 (GPIO7)
DHT_RAW: D5.1, J4.2, R6.2
GND: C1.1, C2.1, C3.1, C4.1, C5.1, C6.1, C11.1, D1.2, D3.2, D4.2, D5.2, D6.2, D7.2, D8.2, D9.2, D10.2, J1.2, J2.3, J3.3, J3.5, J4.3, J5.4, J6.2, J7.2, J8.2, J9.2, J9.3, J9.4, J9.5, J10.2, LED1.1, R17.1, TP3.1, U1.22 (GND), U1.23 (GND), U1.24 (GND), U1.44 (GND), U2.1 (GND), U2.8 (GND), U2.10 (GND), U3.2 (GND), U4.2 (GND)
I2C_SCL_GPIO: R9.1, R11.2, U1.5 (GPIO5)
I2C_SCL_RAW: D7.1, J5.3, R9.2
I2C_SDA_GPIO: R8.1, R10.1, U1.4 (GPIO4)
I2C_SDA_RAW: D6.1, J5.2, R8.2
LDR_ADC: R14.1, R15.1, U1.15 (GPIO9)
LDR_RAW: D9.1, J6.1, R14.2
LORA_ANT: J9.1, U2.9 (ANT)
LORA_DIO0: U1.40 (GPIO2), U2.14 (DIO0)
LORA_DIO1: TP4.1, U2.15 (DIO1)
LORA_MISO: U1.19 (GPIO13), U2.2 (MISO)
LORA_MOSI: U1.17 (GPIO11), U2.3 (MOSI)
LORA_NSS: U1.11 (GPIO18), U2.5 (NSS)
LORA_RST: U1.20 (GPIO14), U2.6 (RESET)
LORA_SCK: U1.18 (GPIO12), U2.4 (SCK)
PWR_LED_A: LED1.2, R1.1
RAIN_GPIO: R2.1, R3.1, U1.6 (GPIO6)
RAIN_RAW: D3.1, J2.4, R2.2
SETUP_RESET: J10.1, U1.31 (GPIO0)
UART_RX: J8.4, U1.42 (GPIO44)
UART_TX: J8.3, U1.43 (GPIO43)
VANE_ADC: R12.1, R13.1, U1.16 (GPIO10)
VANE_RAW: D8.1, J3.2, R12.2
VIN_FUSED: D1.1, D2.2, F1.1
VIN_PROTECTED: C1.2, D2.1, U3.1 (VIN)
VIN_RAW: F1.2, J1.1
WIND_GPIO: R4.1, R5.1, U1.13 (GPIO3)
WIND_RAW: D4.1, J3.4, R4.2

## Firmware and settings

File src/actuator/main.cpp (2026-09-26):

#include <Arduino.h>
#include <SPI.h>
#include <RadioLib.h>
#include <LoraProtocol.h>
#include <Preferences.h>
#include <DeviceIdentity.h>

#ifndef PILOT_MAX_OPEN_S
#define PILOT_MAX_OPEN_S 300
#endif
#ifndef PILOT_MIN_OPEN_BATTERY_MV
#define PILOT_MIN_OPEN_BATTERY_MV 3400
#endif
static_assert(PILOT_MAX_OPEN_S >= 1 && PILOT_MAX_OPEN_S <= 300,
              "Pilot OPEN time must be between 1 and 300 seconds");
static_assert(PILOT_MIN_OPEN_BATTERY_MV >= 3000 && PILOT_MIN_OPEN_BATTERY_MV <= 4200,
              "Pilot battery threshold must be between 3000 and 4200 mV");

const float    LORA_FREQ = 868.0f;
Module loraMod(LORA_CS, LORA_IRQ, LORA_RST, RADIOLIB_NC);
SX1276 radio(&loraMod);
DeviceIdentity identity(DeviceRole::ACTUATOR);
bool radioReady = false;
bool outputsReady = false;

// GPIO23 is the onboard SX1276 reset on TTGO LoRa32 v2.1 and must stay reserved.
const uint8_t AIN1 = 2, AIN2 = 4, PWMA = 12, STBY = 17;
static_assert(AIN1 != LORA_RST && AIN2 != LORA_RST && PWMA != LORA_RST && STBY != LORA_RST,
              "Valve driver pins must not share the onboard LoRa reset pin");
// No position switch is installed on the current 4.5 V latching solenoid.
// 0xFF disables feedback completely; GPIO3 remains available for serial RX.
#ifndef ACTUATOR_VALVE_FB_PIN
#define ACTUATOR_VALVE_FB_PIN 0xFF
#endif
const uint8_t VALVE_FB_PIN = ACTUATOR_VALVE_FB_PIN;
const uint8_t VALVE_FB_OPEN_LEVEL = LOW;
const uint32_t VALVE_PULSE_MS = 30;
bool valveOpen = false;  // Estimated/commanded state when feedback_valid is false.
bool valveCommandedOpen = false;
bool valveFeedbackValid = false;
uint8_t actuatorErrorFlags = 0;
uint32_t valveCloseDeadlineMs = 0;
bool valveCloseTimerArmed = false;  // Separate flag: a valid deadline can wrap to zero.
uint32_t lastSafetyCloseAttemptMs = 0;
const uint16_t DEFAULT_MAX_OPEN_S = PILOT_MAX_OPEN_S;
const uint16_t ABSOLUTE_MAX_OPEN_S = PILOT_MAX_OPEN_S;
const uint32_t SAFETY_CLOSE_RETRY_MS = 5000;
const uint32_t HEARTBEAT_INTERVAL = 30000;
uint32_t lastHbMs = 0;
uint32_t uplinkSeq = 0;
uint32_t uplinkSeqLimit = 0;

enum ActuatorError : uint8_t {
    ACT_ERR_FEEDBACK_MISSING = 0x01,
    ACT_ERR_FEEDBACK_MISMATCH = 0x02,
    ACT_ERR_SAFETY_TIMEOUT = 0x04,
    ACT_ERR_HYDRAULICS_DISABLED = 0x08,
    ACT_ERR_STORAGE = 0x10
};

#ifndef ENABLE_HYDRAULIC_SENSORS
#define ENABLE_HYDRAULIC_SENSORS 0
#endif

const uint8_t FLOW_PIN = 13;
// Use input-only ADC pins that do not overlap the LoRa DIO1/DIO2 lines.
const uint8_t PRESSURE_PIN = 34;
const uint8_t TANK_PIN = 36;
const uint8_t PUMP_CURRENT_PIN = 37;
const float FLOW_PULSES_PER_LITER = 450.0f;
const float PRESSURE_FULL_SCALE_BAR = 10.0f;
const float PUMP_CURRENT_FULL_SCALE_A = 20.0f;
volatile uint32_t flowPulses = 0;
portMUX_TYPE flowMux = portMUX_INITIALIZER_UNLOCKED;
uint32_t lastHydraulicMs = 0;

void IRAM_ATTR onFlowPulse() {
    portENTER_CRITICAL_ISR(&flowMux);
    flowPulses++;
    portEXIT_CRITICAL_ISR(&flowMux);
}

struct HydraulicData {
    uint16_t flowCentiLpm;
    uint16_t pressureKpa;
    uint8_t tankPct;
    uint16_t pumpCurrentMa;
};

HydraulicData readHydraulics() {
    HydraulicData data{UINT16_MAX, UINT16_MAX, UINT8_MAX, UINT16_MAX};
#if ENABLE_HYDRAULIC_SENSORS
    const uint32_t now = millis();
    uint32_t pulses;
    portENTER_CRITICAL(&flowMux);
    pulses = flowPulses;
    flowPulses = 0;
    portEXIT_CRITICAL(&flowMux);
    const float minutes = max(0.001f, (now - lastHydraulicMs) / 60000.0f);
    lastHydraulicMs = now;
    const float flowLpm = (pulses / FLOW_PULSES_PER_LITER) / minutes;
    const float pressureBar = analogRead(PRESSURE_PIN) * PRESSURE_FULL_SCALE_BAR / 4095.0f;
    const float tank = analogRead(TANK_PIN) * 100.0f / 4095.0f;
    const float pumpA = analogRead(PUMP_CURRENT_PIN) * PUMP_CURRENT_FULL_SCALE_A / 4095.0f;
    data.flowCentiLpm = static_cast<uint16_t>(constrain(flowLpm * 100.0f, 0.0f, 65534.0f));
    data.pressureKpa = static_cast<uint16_t>(constrain(pressureBar * 100.0f, 0.0f, 65534.0f));
    data.tankPct = static_cast<uint8_t>(constrain(tank, 0.0f, 100.0f));
    data.pumpCurrentMa = static_cast<uint16_t>(constrain(pumpA * 1000.0f, 0.0f, 65534.0f));
#else
    actuatorErrorFlags |= ACT_ERR_HYDRAULICS_DISABLED;
#endif
    return data;
}

bool readValveFeedback(bool& open) {
    if (VALVE_FB_PIN == 0xFF) return false;
    open = digitalRead(VALVE_FB_PIN) == VALVE_FB_OPEN_LEVEL;
    return true;
}

bool valveSet(bool open, uint16_t timeoutS = DEFAULT_MAX_OPEN_S) {
    valveCommandedOpen = open;
    if (open) {
        // Arm before the first OPEN pulse. Repeated OPEN commands must not
        // extend the original deadline indefinitely.
        if (!valveCloseTimerArmed) {
            const uint16_t safeTimeout = constrain(timeoutS ? timeoutS : DEFAULT_MAX_OPEN_S,
                                                   static_cast<uint16_t>(1), ABSOLUTE_MAX_OPEN_S);
            valveCloseDeadlineMs = millis() + static_cast<uint32_t>(safeTimeout) * 1000UL;
            valveCloseTimerArmed = true;
            lastSafetyCloseAttemptMs = millis() - SAFETY_CLOSE_RETRY_MS;
        }
    }
    digitalWrite(STBY, HIGH);
    digitalWrite(AIN1, open ? HIGH : LOW);
    digitalWrite(AIN2, open ? LOW : HIGH);
    digitalWrite(PWMA, HIGH);
    delay(VALVE_PULSE_MS);
    digitalWrite(PWMA, LOW);
    digitalWrite(AIN1, LOW);
    digitalWrite(AIN2, LOW);
    digitalWrite(STBY, LOW);
    delay(100);

    bool actual = false;
    valveFeedbackValid = readValveFeedback(actual);
    if (valveFeedbackValid) {
        valveOpen = actual;
        actuatorErrorFlags &= ~ACT_ERR_FEEDBACK_MISSING;
        if (actual != open) {
            actuatorErrorFlags |= ACT_ERR_FEEDBACK_MISMATCH;
            if (open) {
                // A failed OPEN verification is ambiguous: a broken feedback
                // wire can report CLOSED even though the valve moved. Send an
                // immediate CLOSE pulse and only stop retrying when CLOSE is
                // verified.
                const bool closeVerified = valveSet(false, 0);
                actuatorErrorFlags |= ACT_ERR_FEEDBACK_MISMATCH;
                // valveSet(false) already disarms a verified close or schedules
                // the next retry. Preserve that schedule instead of turning a
                // feedback fault into a continuous pulse loop.
                (void)closeVerified;
                return false;
            }
            // A failed close with an actually open valve must keep retrying.
            if (!open && actual) {
                valveCloseDeadlineMs = millis() + SAFETY_CLOSE_RETRY_MS;
                valveCloseTimerArmed = true;
            }
            return false;
        }
        actuatorErrorFlags &= ~ACT_ERR_FEEDBACK_MISMATCH;
    } else {
        // Open-loop operation: this is the requested state, not proof of movement.
        valveOpen = open;
        actuatorErrorFlags |= ACT_ERR_FEEDBACK_MISSING;
        actuatorErrorFlags &= ~ACT_ERR_FEEDBACK_MISMATCH;
    }

    if (!open) {
        valveCloseTimerArmed = false;
        valveCloseDeadlineMs = 0;
    }
    return true;
}

void refreshValveFeedback() {
    bool measuredOpen = false;
    valveFeedbackValid = readValveFeedback(measuredOpen);
    if (!valveFeedbackValid) {
        actuatorErrorFlags |= ACT_ERR_FEEDBACK_MISSING;
        return;
    }

    valveOpen = measuredOpen;
    actuatorErrorFlags &= ~ACT_ERR_FEEDBACK_MISSING;
    if (measuredOpen == valveCommandedOpen) {
        actuatorErrorFlags &= ~ACT_ERR_FEEDBACK_MISMATCH;
        return;
    }

    actuatorErrorFlags |= ACT_ERR_FEEDBACK_MISMATCH;
    if (measuredOpen && !valveCommandedOpen && !valveCloseTimerArmed) {
        // A heartbeat discovered an open valve that should be closed. Arm an
        // immediate close; the main loop performs and retries the pulse.
        valveCloseTimerArmed = true;
        valveCloseDeadlineMs = millis();
        lastSafetyCloseAttemptMs = millis() - SAFETY_CLOSE_RETRY_MS;
    }
}

bool valveSafetyCloseDue(uint32_t now) {
    // Do not gate this on valveOpen: false feedback may hide an open valve.
    return valveCloseTimerArmed && static_cast<int32_t>(now - valveCloseDeadlineMs) >= 0 &&
           now - lastSafetyCloseAttemptMs >= SAFETY_CLOSE_RETRY_MS;
}

uint32_t lastSeq = 0;

uint32_t nextPersistentSequence() {
    if (uplinkSeq >= uplinkSeqLimit) {
        Preferences prefs;
        if (!prefs.begin("lora_seq", false)) return 0;
        const uint32_t start = prefs.getULong("next_tx", 1);
        if (start == 0 || start > UINT32_MAX - 1024) { prefs.end(); return 0; }
        const uint32_t reservedLimit = start + 1023;
        const uint32_t nextBlock = reservedLimit + 1;
        const bool reserved = prefs.putULong("next_tx", nextBlock) == sizeof(uint32_t) &&
            prefs.getULong("next_tx", 0) == nextBlock;
        prefs.end();
        if (!reserved) return 0;
        uplinkSeq = start - 1;
        uplinkSeqLimit = reservedLimit;
    }
    return ++uplinkSeq;
}

bool loadReplayState() {
    Preferences prefs;
    if (!prefs.begin("lora_seq", false)) return false;
    lastSeq = prefs.getULong("last_rx", 0);
    prefs.end();
    return true;
}

bool saveReplayState(uint32_t sequence) {
    Preferences prefs;
    if (!prefs.begin("lora_seq", false)) return false;
    const bool saved = prefs.putULong("last_rx", sequence) == sizeof(uint32_t) &&
        prefs.getULong("last_rx", 0) == sequence;
    prefs.end();
    return saved;
}

const uint8_t BATT_PIN = 35;
float readBattery() {
    uint32_t sum = 0;
    for (int i = 0; i < 32; i++) { sum += analogRead(BATT_PIN); delayMicroseconds(50); }
    return (sum / 32.0f / 4095.0f) * 3.3f * 2.0f;
}

void sendAck(uint32_t ackSeq, uint8_t result);
void sendHeartbeat();

void processPacket() {
    if (!identity.ready() || !radioReady) return;
    uint8_t buf[LORA_MAX_PAYLOAD];
    size_t len = radio.getPacketLength();
    if (len < LORA_HEADER_SIZE + MIC_SIZE || len > sizeof(buf)) return;
    int st = radio.readData(buf, len);
    if (st != RADIOLIB_ERR_NONE) return;

    uint16_t target = (buf[0] << 8) | buf[1];
    Serial.printf("[AN] Rx %u bytes target=%04X RSSI=%.1f\n", len, target, radio.getRSSI());
    if (target != identity.nodeId()) return;

    uint8_t pktType = buf[NODE_ID_SIZE + IV_NONCE_SIZE];
    uint32_t seq = 0;
    for (int i = 0; i < 8; i++) seq = (seq << 8) | buf[NODE_ID_SIZE + 4 + i];
    size_t ctLen = len - LORA_HEADER_SIZE - MIC_SIZE;

    Serial.printf("[AN] pktType=0x%02X seq=%u ctLen=%u\n", pktType, seq, (unsigned)ctLen);

    if (pktType != static_cast<uint8_t>(PacketType::ACTUATOR_COMMAND) || ctLen != COMMAND_WIRE_SIZE) {
        Serial.printf("[AN] Invalid command frame type=0x%02X len=%u\n", pktType, (unsigned)ctLen);
        return;
    }

    const uint8_t* iv = buf + NODE_ID_SIZE;
    const uint8_t* ct = buf + LORA_HEADER_SIZE;
    const uint8_t* mic = ct + ctLen;

    uint8_t pt[LORA_MAX_CIPHERTEXT];
    memcpy(pt, ct, ctLen);

    LoraCrypto crypto;
    crypto.setKey(identity.psk(), AES128_KEY_SIZE);
    CryptoResult cr = crypto.decrypt(pt, ctLen, pktType, seq, identity.nodeId(), iv, mic);
    if (cr != CryptoResult::OK) {
        Serial.printf("[AN] DECRYPT_FAIL err=%d seq=%u pktType=0x%02X ctLen=%u\n",
                      (int)cr, seq, pktType, (unsigned)ctLen);
        return;
    }

    ActuatorCommand cmd;
    deserializeCommand(pt, cmd);
    if (cmd.sequence != seq) { Serial.println(F("[AN] Command sequence mismatch")); return; }
    if (seq <= lastSeq) { Serial.printf("[AN] Replay %u (last=%u)\n", seq, lastSeq); return; }
    const bool validCommand = cmd.command == 0x01 && cmd.value <= 1 &&
        ((cmd.value == 0 && cmd.timeout_s == 0) ||
         (cmd.value == 1 && cmd.timeout_s >= 1 && cmd.timeout_s <= ABSOLUTE_MAX_OPEN_S));
    if (!validCommand) {
        Serial.printf("[AN] Invalid authenticated command cmd=0x%02X value=%u timeout=%u\n",
                      cmd.command, cmd.value, cmd.timeout_s);
        sendAck(cmd.sequence, ACTUATOR_RESULT_INVALID_COMMAND);
        return;
    }
    if (!saveReplayState(seq)) {
        actuatorErrorFlags |= ACT_ERR_STORAGE;
        Serial.println(F("[AN] Command rejected: replay state could not be persisted"));
        sendAck(cmd.sequence, ACTUATOR_RESULT_STORAGE_ERROR);
        return;
    }
    lastSeq = seq;
    actuatorErrorFlags &= ~ACT_ERR_STORAGE;
    Serial.printf("[AN] cmd: seq=%u cmd=0x%02X val=%u timeout=%u\n",
                  cmd.sequence, cmd.command, cmd.value, cmd.timeout_s);

    if (cmd.command == 0x01) {
        const uint16_t batteryMv = static_cast<uint16_t>(readBattery() * 1000.0f);
        if (cmd.value != 0 && (batteryMv < PILOT_MIN_OPEN_BATTERY_MV || batteryMv > 5000U)) {
            Serial.printf("[AN] OPEN rejected: battery reading %u mV is outside pilot limits\n", batteryMv);
            sendAck(cmd.sequence, ACTUATOR_RESULT_LOW_BATTERY);
            return;
        }
        const bool ok = valveSet(cmd.value != 0, cmd.timeout_s);
        Serial.printf("[AN] Valve command=%s state=%s feedback=%s result=%s\n",
                      valveCommandedOpen ? "OPEN" : "CLOSED", valveOpen ? "OPEN" : "CLOSED",
                      valveFeedbackValid ? "AVAILABLE" : "UNAVAILABLE",
                      !ok ? "FEEDBACK_MISMATCH" : (valveFeedbackValid ? "VERIFIED" : "PULSE_SENT_UNVERIFIED"));
        const uint8_t result = !ok ? ACTUATOR_RESULT_FEEDBACK_MISMATCH
            : (valveFeedbackValid ? ACTUATOR_RESULT_VERIFIED : ACTUATOR_RESULT_UNVERIFIED);
        sendAck(cmd.sequence, result);
    }
}

bool serviceIdentityConsole() {
    const IdentityEvent event = identity.serviceConsole(Serial);
    if (event == IdentityEvent::NONE) return false;
    if (outputsReady) valveSet(false);
    if (radioReady) radio.sleep();
    Serial.println(F("[AN] Restarting after identity change"));
    Serial.flush();
    delay(100);
    ESP.restart();
    return true;
}

void printProvisioningHelp() {
    identity.printStatus(Serial);
    if (identity.state() == IdentityState::EMPTY) {
        Serial.println(F("[AN] Radio disabled. Use: PROVISION 0002 <32-hex-PSK>"));
    } else if (identity.state() == IdentityState::CORRUPT ||
               identity.state() == IdentityState::ROLE_MISMATCH) {
        Serial.println(F("[AN] Radio disabled. Use: ERASE CORRUPT CONFIRM"));
    } else {
        Serial.println(F("[AN] Identity storage unavailable; radio remains disabled"));
    }
}

void setup() {
    Serial.begin(115200); delay(100);
    Serial.printf("[AN] Pins: LoRaRST=%u AIN1=%u AIN2=%u PWMA=%u STBY=%u pulse=%ums\n",
                  LORA_RST, AIN1, AIN2, PWMA, STBY, VALVE_PULSE_MS);

    pinMode(AIN1, OUTPUT); pinMode(AIN2, OUTPUT);
    pinMode(PWMA, OUTPUT); pinMode(STBY, OUTPUT);
    digitalWrite(AIN1, LOW); digitalWrite(AIN2, LOW);
    digitalWrite(PWMA, LOW); digitalWrite(STBY, LOW);
    outputsReady = true;
    if (VALVE_FB_PIN != 0xFF) pinMode(VALVE_FB_PIN, INPUT_PULLUP);
#if ENABLE_HYDRAULIC_SENSORS
    pinMode(FLOW_PIN, INPUT_PULLUP);
    pinMode(PRESSURE_PIN, INPUT);
    pinMode(TANK_PIN, INPUT);
    pinMode(PUMP_CURRENT_PIN, INPUT);
    attachInterrupt(digitalPinToInterrupt(FLOW_PIN), onFlowPulse, FALLING);
#endif
    analogReadResolution(12);
    lastHydraulicMs = millis();

    bool bootValveState = false;
    valveFeedbackValid = readValveFeedback(bootValveState);
    valveOpen = valveCommandedOpen = valveFeedbackValid ? bootValveState : false;
    if (!valveFeedbackValid) {
        actuatorErrorFlags |= ACT_ERR_FEEDBACK_MISSING;
        // A latching valve can remain open across MCU resets. Establish a
        // commanded closed state without pretending a position was measured.
        Serial.println(F("[AN] No position feedback: boot CLOSE pulse; position UNVERIFIED"));
        valveSet(false);
    } else if (valveOpen) {
        actuatorErrorFlags |= ACT_ERR_SAFETY_TIMEOUT;
        valveSet(false);
    }

    identity.begin();
    if (!identity.ready()) {
        printProvisioningHelp();
        return;
    }
    Serial.printf("[AN] Actuator Node %04X starting\n", identity.nodeId());
    if (!loadReplayState()) {
        actuatorErrorFlags |= ACT_ERR_STORAGE;
        Serial.println(F("[AN] Replay storage unavailable; radio remains disabled"));
        return;
    }

    SPI.begin(LORA_SCK, LORA_MISO, LORA_MOSI, LORA_CS);
    int st = radio.begin(LORA_FREQ, 125.0f, 9, 5,
                          RADIOLIB_SX127X_SYNC_WORD, 10, 12);
    if (st != RADIOLIB_ERR_NONE) {
        Serial.printf("[AN] LoRa error: %d\n", st);
    } else {
        radioReady = true;
        Serial.println(F("[AN] LoRa ready"));
        radio.startReceive();
        sendHeartbeat();
        lastHbMs = millis();
    }
}

void loop() {
    if (serviceIdentityConsole()) return;
    uint32_t now = millis();
    if (valveSafetyCloseDue(now)) {
        lastSafetyCloseAttemptMs = now;
        actuatorErrorFlags |= ACT_ERR_SAFETY_TIMEOUT;
        const bool closed = valveSet(false);
        if (!closed) {
            Serial.println(F("[AN] Safety close feedback mismatch; retry scheduled"));
        } else {
            Serial.println(valveFeedbackValid ? F("[AN] Safety timeout: CLOSED verified")
                                             : F("[AN] Safety timeout: CLOSE pulse sent; position UNVERIFIED"));
        }
        if (identity.ready() && radioReady) {
            sendHeartbeat();
            lastHbMs = now;
            radio.startReceive();
        }
    }
    if (!identity.ready() || !radioReady) { delay(20); return; }
    uint16_t irqFlags = radio.getIRQFlags();
    if ((irqFlags & RADIOLIB_SX127X_CLEAR_IRQ_FLAG_RX_DONE) && radio.getPacketLength() > 0) {
        processPacket();
        radio.startReceive();
    }
    now = millis();
    if (now - lastHbMs >= HEARTBEAT_INTERVAL) {
        lastHbMs = now;
        sendHeartbeat();
        radio.startReceive();
    }
    delay(10);
}

void sendHeartbeat() {
    if (!identity.ready() || !radioReady) return;
    refreshValveFeedback();
    uint32_t txSeq = nextPersistentSequence();
    if (txSeq == 0) { Serial.println(F("[AN] Sequence space exhausted")); return; }
    HeartbeatPayload hb{};
    hb.sequence    = txSeq;
    hb.battery_mv  = (uint16_t)(readBattery() * 1000);
    hb.valve_state = valveOpen ? 1 : 0;
    hb.valve_commanded = valveCommandedOpen ? 1 : 0;
    hb.feedback_valid = valveFeedbackValid ? 1 : 0;
    const HydraulicData hydraulic = readHydraulics();
    hb.error_flags = actuatorErrorFlags;
    hb.flow_centi_lpm = hydraulic.flowCentiLpm;
    hb.pressure_kpa = hydraulic.pressureKpa;
    hb.tank_pct = hydraulic.tankPct;
    hb.pump_current_ma = hydraulic.pumpCurrentMa;

    uint8_t pt[HEARTBEAT_WIRE_SIZE];
    serializeHeartbeat(pt, hb);

    LoraCrypto crypto;
    crypto.setKey(identity.psk(), AES128_KEY_SIZE);

    uint8_t iv[GCM_IV_SIZE], mic[MIC_SIZE];
    CryptoResult cr = crypto.encrypt(pt, HEARTBEAT_WIRE_SIZE,
                                      (uint8_t)PacketType::HEARTBEAT,
                                      txSeq, identity.nodeId(), iv, mic);
    if (cr != CryptoResult::OK) { Serial.printf("[AN] HB encrypt err=%d\n", (int)cr); return; }

    uint8_t tx[LORA_MAX_PAYLOAD]; size_t o = 0;
    const uint16_t nodeId = identity.nodeId();
    uint8_t node_be[2] = { uint8_t(nodeId >> 8), uint8_t(nodeId & 0xFF) };
    memcpy(tx+o, node_be, 2); o+=2;
    memcpy(tx+o, iv, 12);     o+=12;
    tx[o++] = (uint8_t)PacketType::HEARTBEAT;
    memcpy(tx+o, pt, HEARTBEAT_WIRE_SIZE); o+=HEARTBEAT_WIRE_SIZE;
    memcpy(tx+o, mic, MIC_SIZE);           o+=MIC_SIZE;

    int st = radio.standby(); if (st != 0) return;
    radio.setFrequency(LORA_FREQ);
    st = radio.transmit(tx, o);
    Serial.printf("[AN] HB seq=%u commanded=%s feedback=%s flags=0x%02X tx=%s\n",
                  hb.sequence, valveCommandedOpen ? "OPEN" : "CLOSED",
                  valveFeedbackValid ? "AVAILABLE" : "UNAVAILABLE", hb.error_flags,
                  st == RADIOLIB_ERR_NONE ? "OK" : "FAIL");
}

void sendAck(uint32_t ackSeq, uint8_t result) {
    if (!identity.ready() || !radioReady) return;
    uint32_t txSeq = nextPersistentSequence();
    if (txSeq == 0) { Serial.println(F("[AN] Sequence space exhausted")); return; }
    AckPayload ack{};
    ack.ack_seq    = ackSeq;
    ack.result     = result;
    ack.battery_mv = (uint16_t)(readBattery() * 1000);
    ack.valve_state = valveOpen ? 1 : 0;
    ack.feedback_valid = valveFeedbackValid ? 1 : 0;
    ack.error_flags = actuatorErrorFlags;

    uint8_t pt[ACK_WIRE_SIZE];
    serializeAck(pt, ack);

    LoraCrypto crypto;
    crypto.setKey(identity.psk(), AES128_KEY_SIZE);

    uint8_t iv[GCM_IV_SIZE], mic[MIC_SIZE];
    CryptoResult cr = crypto.encrypt(pt, ACK_WIRE_SIZE,
                                      (uint8_t)PacketType::ACK,
                                      txSeq, identity.nodeId(), iv, mic);
    if (cr != CryptoResult::OK) { Serial.printf("[AN] ACK encrypt err=%d\n", (int)cr); return; }

    uint8_t tx[LORA_MAX_PAYLOAD]; size_t o = 0;
    const uint16_t nodeId = identity.nodeId();
    uint8_t node_be[2] = { uint8_t(nodeId >> 8), uint8_t(nodeId & 0xFF) };
    memcpy(tx+o, node_be, 2); o+=2;
    memcpy(tx+o, iv, 12);     o+=12;
    tx[o++] = (uint8_t)PacketType::ACK;
    memcpy(tx+o, pt, ACK_WIRE_SIZE); o+=ACK_WIRE_SIZE;
    memcpy(tx+o, mic, MIC_SIZE);     o+=MIC_SIZE;

    int st = radio.standby(); if (st != 0) return;
    radio.setFrequency(LORA_FREQ);
    st = radio.transmit(tx, o);
    Serial.printf("[AN] ACK seq=%u result=0x%02X feedback=%s tx=%s\n",
                  ackSeq, result, valveFeedbackValid ? "AVAILABLE" : "UNAVAILABLE",
                  st == RADIOLIB_ERR_NONE ? "OK" : "FAIL");
}

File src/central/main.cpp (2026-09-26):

#include <Arduino.h>
#include <WiFi.h>
#include <ESPmDNS.h>
#include <SPI.h>
#include <RadioLib.h>
#include <PicoMQTT.h>
#include <Preferences.h>
#include <LoraProtocol.h>
#include <MqttTopics.h>
#include <WebDashboard.h>
#include "WiFiManager.h"
#include "WeatherStation.h"
#include "NodeManager.h"
#include "CloudClient.h"
#include "DataLogger.h"
#include "FieldConfigManager.h"
#include "TimeService.h"
#include "EdgeAIEngine.h"
#include "EdgeAIModel.h"
#include <mutex>
#include <cmath>
#include <esp_system.h>
#include "RuntimeDiagnostics.h"

// Inference, JSON serialization and dataset records must not run on the small
// radio task stack. Arduino's loop owns this work and the MQTT broker.
SET_LOOP_TASK_STACK_SIZE(16 * 1024);

#ifndef PILOT_MAX_OPEN_S
#define PILOT_MAX_OPEN_S 300
#endif
#ifndef PILOT_REQUIRE_FEEDBACK_FOR_AUTO_OPEN
#define PILOT_REQUIRE_FEEDBACK_FOR_AUTO_OPEN 1
#endif
#ifndef PILOT_ENABLE_LOCAL_MQTT
#define PILOT_ENABLE_LOCAL_MQTT 0
#endif
#ifndef PILOT_ENABLE_WEB_OTA
#define PILOT_ENABLE_WEB_OTA 0
#endif
#ifndef PILOT_ENABLE_CLOUD_OPEN
#define PILOT_ENABLE_CLOUD_OPEN 0
#endif
static_assert(PILOT_MAX_OPEN_S >= 1 && PILOT_MAX_OPEN_S <= 300,
              "Pilot OPEN time must be between 1 and 300 seconds");

const float    LORA_FREQ  = 868.0f;
const uint32_t WEATHER_INTERVAL_MS = 30000;
const uint16_t ACTUATOR_MAX_RUNTIME_S = PILOT_MAX_OPEN_S;
const float AUTO_HYSTERESIS_PCT = 3.0f;
const uint32_t PILOT_ACTUATOR_FRESH_MS = 90000UL;
const uint32_t PILOT_SENSOR_FAIL_CLOSE_MS = 5UL * 60UL * 1000UL;
const uint32_t PILOT_SAFETY_CLOSE_RETRY_MS = 30000UL;
const uint8_t  LORA_NSS = 18, LORA_DIO0 = 2, LORA_RST = 14;
const uint8_t  RAIN_PIN = 6, WIND_PIN = 3, VANE_PIN = 10;
const uint8_t  DHT_PIN  = 7, LDR_PIN  = 9, BATT_PIN = 8;
const uint8_t  I2C_SDA  = 4, I2C_SCL  = 5;

Module loraMod(LORA_NSS, LORA_DIO0, LORA_RST, RADIOLIB_NC);
SX1276 radio(&loraMod);
PicoMQTT::Server mqttBroker(1883);
AsyncWebServer webServer(80);
WebDashboard dashboard;
WeatherStation weather(RAIN_PIN, WIND_PIN, VANE_PIN, DHT_PIN, LDR_PIN, BATT_PIN, I2C_SDA, I2C_SCL);
NodeManager nodeMgr;
CloudClient cloud;
WiFiManager wifiManager;
DataLogger dataLogger;
FieldConfigManager fieldConfig;
TimeService timeService;
EdgeAIEngine edgeAI;

uint32_t downlinkSeq = 0;
uint32_t downlinkSeqLimit = 0;
QueueHandle_t loraTxQueue = NULL;
QueueHandle_t loraRxQueue = NULL;
QueueHandle_t cloudReqQueue = NULL;
SemaphoreHandle_t stateMutex = NULL;
volatile bool loraReady = false;
bool dashboardReady = false;
bool mqttReady = false;
TaskHandle_t loraTaskHandle = nullptr;
TaskHandle_t cloudTaskHandle = nullptr;
std::mutex fieldConfigMutex;
volatile uint32_t loraRxDropped = 0;

struct LoraRxItem {
    uint8_t data[LORA_MAX_PAYLOAD];
    size_t len;
    int16_t rssi;
};

struct LoraTxItem {
    uint8_t data[LORA_MAX_PAYLOAD];
    size_t len;
};

struct PendingCommand {
    uint32_t radioSeq;
    uint32_t cloudCmdId;
    uint16_t nodeId;
    bool desiredState;
    uint16_t timeoutS;
    uint32_t createdMs;
    char source[16];
    bool valid;
};

static constexpr size_t PENDING_COMMAND_CAPACITY = NodeManager::MAX_NODES * 2;
PendingCommand pendingCommands[PENDING_COMMAND_CAPACITY] = {};

enum class CloudCommandState : uint8_t { EMPTY, PENDING, COMPLETE };

struct CloudCommandRecord {
    uint32_t commandId = 0;
    uint16_t nodeId = 0;
    CloudCommandState state = CloudCommandState::EMPTY;
    bool desiredState = false;
    bool ok = false;
    float batteryV = NAN;
    bool valveActual = false;
    bool feedbackValid = false;
    uint8_t errorFlags = 0;
    uint64_t epochMs = 0;
    uint32_t updatedMs = 0;
};

enum class CloudCommandLookup : uint8_t { NEW_COMMAND, PENDING, COMPLETE, RETRY_CLOSE };

CloudCommandRecord cloudCommandRecords[32] = {};
size_t cloudCommandCursor = 0;

uint32_t nextDownlinkSequence() {
    if (!stateMutex || xSemaphoreTake(stateMutex, pdMS_TO_TICKS(500)) != pdTRUE) return 0;
    if (downlinkSeq >= downlinkSeqLimit) {
        Preferences prefs;
        if (!prefs.begin("lora_seq", false)) { xSemaphoreGive(stateMutex); return 0; }
        const uint32_t start = prefs.getULong("next_tx", 0x80000000UL);
        if (start < 0x80000000UL || start > UINT32_MAX - 1024) {
            prefs.end(); xSemaphoreGive(stateMutex); return 0;
        }
        const uint32_t reservedLimit = start + 1023;
        const uint32_t nextBlock = reservedLimit + 1;
        const bool reserved = prefs.putULong("next_tx", nextBlock) == sizeof(uint32_t) &&
            prefs.getULong("next_tx", 0) == nextBlock;
        prefs.end();
        if (!reserved) { xSemaphoreGive(stateMutex); return 0; }
        downlinkSeq = start - 1;
        downlinkSeqLimit = reservedLimit;
    }
    uint32_t result = ++downlinkSeq;
    xSemaphoreGive(stateMutex);
    return result;
}
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

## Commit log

2026-07-02 Initial commit: LoRa star network with Central Gateway (TTGO/S3), Sensor Node, Actuator Node - SX1276 868MHz, AES-128-GCM encryption, MQTT, WebDashboard
2026-07-05 Update moisture calibration: dry=2500 wet=400, add moisture_pct to packet struct
2026-07-05 Fix ESP32-S3 central pins: CS=10, RST=9, SCK=12, MOSI=11, MISO=13, DIO0=2, DIO1=NC; move weather pins to 14,15,16 to avoid SPI conflict; guard WeatherStation with #ifndef TTGO_GATEWAY
    [main.cpp]
2026-07-05 Switch ESP32-S3 to radio.receive() blocking mode (matches verified test), update pins, guard WeatherStation
2026-07-05 Fix compile: remove unsupported 3rd arg from radio.receive()
    [main.cpp]
2026-07-05 Add remove sensor feature: NodeManager::remove(), WebSocket remove_node handler, dashboard Remove button
2026-07-05 Fix: non-blocking Rx with startReceive/available/readData for dashboard responsiveness
    [main.cpp]
2026-07-06 Actuator: TB6612FNG driver for latching electrovane - AIN1=2, AIN2=4, PWMA=16, STBY=17, 30ms pulse
2026-07-06 Add restart button, wiring diagram (docs/WIRING.md), battery divider values (100k+100k)
2026-07-06 Change actuator PWMA from GPIO 16 to GPIO 23
2026-07-06 Fix S3 Rx via IRQ register poll, add actuator auto-control (threshold + auto-mode)
    - ESP32-S3: poll IRQ flags register directly instead of relying on DIO0/available()
    - NodeInfo: add autoMode, threshold, sensorId fields persisted in NVS
    - NodeManager: setActuatorConfig() to update actuator auto-control params
    - WebDashboard: set_actuator_config WS action + ActuatorCfgCallback
    - main.cpp: checkAutoControl() toggles valve based on moisture vs threshold
    - Dashboard: actuator cards now show auto toggle + threshold slider + sensor ID
    - Nodes table: add Auto/Thr columns
    [main.cpp]
2026-07-06 Refactor: fix bugs, remove dead code, enhance dashboard
    - Bug: sensor & actuator both used NODE_ID=0x0002 (sensor→0x0001)
    - Bug: actuator ACK reused cmd seq for nonce (now independent counter)
    - Bug: WeatherStation race condition in counter read (both counters verified)
    - Dead code: removed LoraProtocol.h/.cpp (unused abstraction layer)
    - Dead code: removed NodeManager::sendCmd() stub
    - Dead code: removed unused PacketType enum values
    - Perf: DS18B20 async conversion (eliminated 750ms blocking delay)
    - Perf: valve state tracked in NodeInfo struct (fragile array removed)
    - Dashboard: modern dark theme with CSS variables + transitions
    - Dashboard: live moisture sparkline charts on sensor car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
    [WeatherStation.cpp, main.cpp]
2026-07-07 fix: actuator RxDone stale-read loop, gateway retries, dashboard toggle; docs: design documents
    - Actuator: gate processPacket on RxDone IRQ flag to prevent infinite
    stale RxNbBytes read loop that flooded serial with decrypt failures
    - Gateway: reduce downlink retries from 3 to 1 (single retry on failure)
    - Dashboard: fix toggleAct JS always sending value:true regardless of state
    - Add docs: software-technical-design.md, embedded-technical-design.md,
    clean-code-guidelines.md, repo-cleanup-report.md
    - Add archive/ with archival policy
    - Add test/test_ttgo.cpp stub for build filter
    - Add lora_protocol shared library
    - Remove unused LoraNetwork.h aggregator
    - Clean up platformio.ini PSRAM c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
    [main.cpp]
2026-07-13 Performance optimization + bug fixes: remove heap allocs in hot paths, fix TTGO build, RSSI capture, temperature precision, JSON injection guards, cloudTask stack
    [WeatherStation.cpp, main.cpp]
2026-08-28 feat: publish complete AMR LoRa irrigation platform
    Include the ESP32-S3 central gateway, LoRa sensor and actuator nodes, dashboard, Edge AI dataset and model tooling, KiCad PCB, SolidWorks actuator assembly, motion study, documentation, and manufactu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
    [01_Lower_Base_Plate.SLDPRT, 01_Lower_Base_Plate.STEP, 01_Lower_Base_Plate.dxf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]
